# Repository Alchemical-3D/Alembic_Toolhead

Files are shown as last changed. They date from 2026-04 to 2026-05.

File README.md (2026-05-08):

<div align="center">

# 🧪 Alembic Toolhead







A highly specialized, ultra-lightweight toolhead designed for the Alchemical-3D ecosystem and A3DP gantry kits. Alembic replaces bulky fans with a rigid, compressed-air cooling architecture.  This toolhead is currently in the Alpha phase of development with working models.  Please review our **[Alpha State & Development Direction](ALPHA_&_DIRECTION.md)** document for more details on support, the project roadmap, and how to provide feedback.

<p align="center">
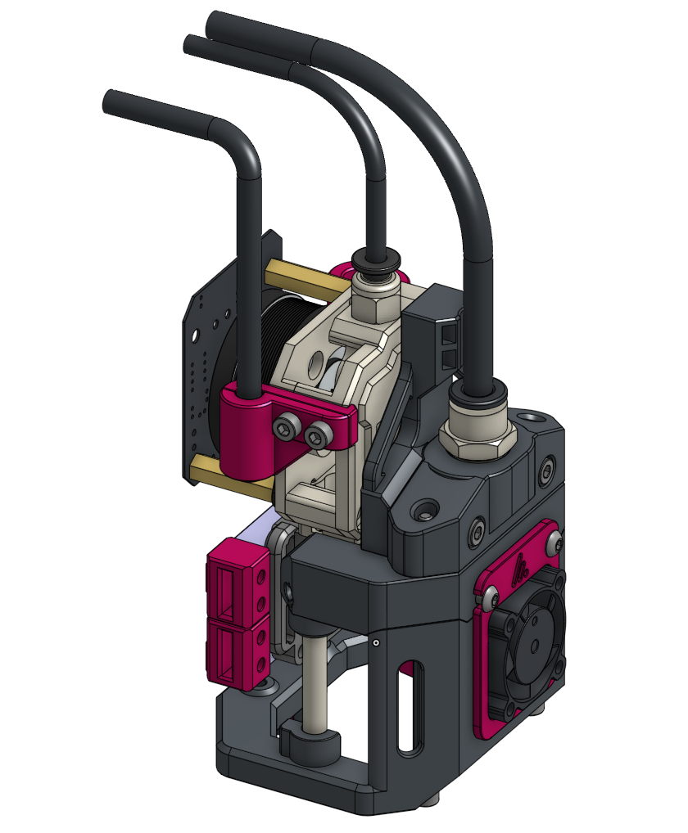
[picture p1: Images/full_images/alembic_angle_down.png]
Alembic Angle Down
  
  &nbsp;
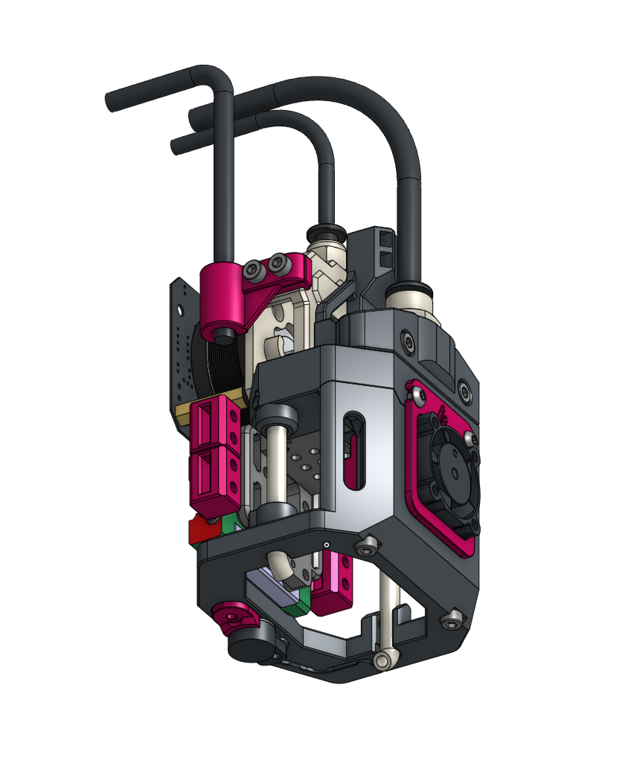
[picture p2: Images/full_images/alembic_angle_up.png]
Alembic Angle Up
  
</p>

**[Bill of Materials](BOM.md)** &nbsp;•&nbsp; **[Assembly Guide](Assembly_Guide.md)** &nbsp;•&nbsp; **[Print Settings](Print_Settings.md)**

</div>

<br>

---

## 🌬️ The Philosophy of Alembic

Alembic differentiates itself by dropping traditional bulky 4010 or 5015 part cooling fans entirely. Instead, it utilizes remote compressed air delivered through a pneumatic tube for high-performance part cooling. 

By integrating aluminum tubing directly into the structural integrity of the carriage, Alembic achieves a design that is incredibly lightweight, surprisingly rigid, and maximally compact—offering unobstructed visibility of the nozzle during layering.

> [!NOTE]
> **Sledgehammer vs. Scalpel**<br>
> *"While traditional systems focus on brute-forcing CFM to wash the area with ambient cooling, Alembic focuses on exact air placement and extreme air speed to achieve superior results. Where CPAP configs are the sledgehammer... Alembic is the scalpel."*

## ✨ Key Specifications & Features

- **Primary Extruder Support:** Initial geometry tailored for the **A3DP FXD**, but is being adopted for a wide range of support.
- **Standard Hotend:** Pre-configured for the **Takoto Hotend** but is being adopted for a wide range of support.
- **Part Cooling:** High-speed compressed air via a `6mm OD x 4mm ID` pneumatic tube pipeline. 
- **Hotend Cooling:** Powered efficiently by a single lightweight **2510 fan** *(for now...)*.
- **Umbilical Management:** Features dedicated, secure routing channels for **Chainflex (CAN/USB wiring)**, the primary pneumatic airline, and the PTFE filament tube.

> [!TIP]
> **Pneumatics and Compatible Systems**<br>
> *This toolhead uses pressurized air (similar to quiet aquarium or medical equipment pumps, rather than loud shop compressors). If you're interested in this project, check out the **[Pneuma Part Cooling](https://github.com/Alchemical-3D/Pneuma_Remote_Air)** project! It is a companion project from Alchemical-3D that provides a professional, quiet, and high-performance pneumatic air supply designed specifically to integrate seamlessly with Alembic.*

---

## 📚 Documentation Index

Everything you need to successfully replicate Alembic on your own machine:

| Category | Description |
| :--- | :--- |
| 📋 **[Bill of Materials (BOM)](BOM.md)** | The comprehensive checklist of printed parts, heat sets, hardware, and pneumatics needed. |
| 🛠️ **[Assembly Guide](Assembly_Guide.md)** | A fully-illustrated, step-by-step mastercloth for putting the Alembic together safely. |
| ⚙️ **[Print Settings](Print_Settings.md)** | Essential slicer configurations, material recommendations, and orientation rules. |
| 🧭 **[Alpha State & Direction](ALPHA_&_DIRECTION.md)** | Current hardware support, active development roadmap, and how to provide feedback. |

---

## 📸 Quick Glimpse

<p align="center">
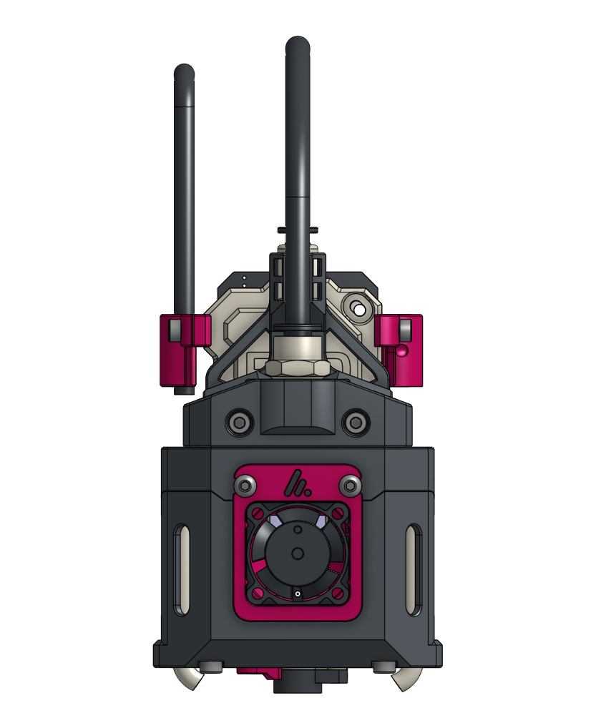
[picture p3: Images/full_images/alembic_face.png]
Alembic Face View
  
</p>

***

## ⚖️ License

This project is licensed under the **Creative Commons Attribution-NonCommercial-ShareAlike 4.0 International License**. See the [LICENSE.md](LICENSE.md) file for details.

***

> ☕ **Did you find this guide helpful?** 
> 
> My projects are open-source and free for the community. If you've enjoyed my designs and want to support my work, consider [leaving me a tip on Ko-fi](https://ko-fi.com/alchemical3d)! 
>
>

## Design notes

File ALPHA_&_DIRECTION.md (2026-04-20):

# 🧭 Alembic Toolhead: Alpha State & Development Direction

Alembic is currently in an active **Alpha State** of development. This document outlines the current state of the project, upcoming features, and intended paths forward as we progress toward a Beta release.

> [!WARNING]
> **Active Development Notice**  
> While we have working models that perform exceptionally well in testing, this toolhead is still evolving. Builders taking on the Alpha release should be prepared for changes to geometry, hardware requirements, or bill of materials (BOM) as the project matures.

---

## 🏗️ Current State (Alpha)

The Alembic Toolhead has proven the viability of utilizing high-speed, remote compressed air for precise high speed part cooling rather than traditional blowers. 

### Current Hardware Compatibility

- **Extruders:** Currently designed for the **A3DP FXD** extruder.
- **Hotends:** Direct support built-in for the **Takoto** and **Dragon** hotends. 

We expect hardware compatibility to widen significantly throughout alpha and beta testing.

---

## 🗺️ Roadmap & Intended Changes

As we prepare the transition from Alpha to Beta, significant improvements are being evaluated and staged. Below is an active list of concepts and intended upgrades going forward:

> [!NOTE]
> ### 📝 Highlighted Concepts & Planned Features
> 
> *The following are concepts, modular expansions, and hardware additions currently under active investigation and development.*
> 
> - **Expanded Extruder Compatibility:** Designing adapters and core mounts to support a wider array of popular extruders beyond the A3DP FXD.
> - **Expanded Hotend Compatibility:** Bringing support for additional high-flow and standard hotends beyond Takoto and Dragon. 
> - **Airflow Optimization:** Continuous iterations and tuning to the internal pneumatic routing to maximize cooling efficiency.
> - **Weight Reduction & Structural Tuning:** Refining the carriage geometry to shave off extra grams without sacrificing the rigidity.

*(Note: Features and concepts listed here are subject to change based on testing constraints, empirical results, and community feedback.)*

---

## 📣 We Need Your Feedback!

Because Alembic relies heavily on unconventional methodology, **community feedback is exceptionally helpful** for optimizing the performance of the toolhead.

If you are an Alpha builder or are interested in the project, we want to hear from you! Please share your prints, airflow observations, and suggestions for improvements.

### Join the Conversation

All development discussion, testing feedback, and suggestions should be directed to our community Discord server.

👉 **Join the discussion in the `#alembic-toolhead` channel on the Alchemical-3D Discord!**

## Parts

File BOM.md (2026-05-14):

# Bill of Materials (BOM)

This list contains all the 3D-printed and physical hardware required to assemble the Alembic Toolhead.

*Note: This document contains affiliate links. Sourcing your parts through these links helps support the continued development of this and other projects at no cost to you, and in some cases gets a discount!*

*Note: Quantities for some hardware fasteners (e.g. M3 screws, heat inserts) are estimates and may be slightly higher/lower based on your exact A3DP FXD extruder/carriage configuration.*

## 1. Printed Parts
Print these out using the guidelines specified in the [Print Settings](Print_Settings.md) page.

| Part File Name | Qty | Description / Notes |
| --- | :---: | --- |
| `Lower_Body.stl` | 1 | Main lower chassis. |
| `Manifold_Frame.stl` | 1 | Pneumatic cooling mechanisms. |
| `Fan_Baffle_Takoto.stl` | 1 | Specifically for the Takoto. |
| `Chainflex_Clamp_Main.stl` | 1 | Top clamp for the electrical umbilical. |
| `Chainflex_Clamp_Base.stl` | 1 | Base support for the electrical umbilical. |
| `Pnuematic_Strain_Relief.stl`| 1 | Secures the pneumatic tube. |
| `Sensor_Retainer.stl` | 1 | Retains BDsensor. (optional) |
| `BD_Mod_Clamp.stl` | 1 | Mod clamp for BDsensor. (optional) |
| `Shim_06mm_BDsensor.stl` | 1 | 0.6mm shim for BDsensor offset. (optional) |
| `Bend_Tool_Base.stl` | 1 | Jig tool base for bending tubing. |
| `Bend_Tool_Lever.stl` | 1 | Jig tool lever for bending tubing. |

## 2. Fasteners & Physical Hardware

| Item | Qty (Est.) | Description |
| --- | :---: | --- |
| **[M3 Heat Set Inserts](https://kb-3d.com/store/inserts-fasteners-adhesives/278-brass-heat-set-threaded-insert-for-plastic-m3x5x4mm.html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)** | ~4 | Standard M3 (typically 5mm x 4mm). Needed at Intake and Strain Relief. |
| **[M3 x 65mm Cap/Button Head](https://amzn.to/4vQRHtp)** | ~2 | Full length of the toolhead carriage, vertically. |
| **[M3 x 8mm Cap/Button Head](https://amzn.to/3QIvw8G)** | ~8 | General assembly screws. |
| **[M3 x 20mm Cap/Button Head](https://amzn.to/3QIvw8G)** | ~2 | For securing the pneumatic strain relief. |
| **[M3 x 24mm Cap/Button Head](https://amzn.to/3QIvw8G)**| ~2 | Passing through front of fan baffle and manifold into the carriage. |
| **[M3 Grub Screws](https://kb-3d.com/store/inserts-fasteners-adhesives/870-alloy-set-screw-m3-x-05-x-4mm-cup-point-1656776837904.html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)** | ~2 | Secure the aluminum tubes into the lower body. |
| **[Aluminum Tube 5mm OD x 3mm](https://amzn.to/4ntsNw5)** | 2 |~ 55mm ID Aluminum tube. |
| **[O-Ring 9x2 (23/64 x 5/64)"](https://amzn.to/4d411CT)** | 2 | For pneumatic sealing. Check diameter against the printed groove. |
| **[PTFE Bowden Fitting](https://kb-3d.com/store/e3d/313-e3d-threaded-bowden-coupling-175-1644689893776.html?affp=6182)** | 1 | PC4-M10 Bowden Pass-Through |
| **[Part Cooling Tube](https://amzn.to/4cFbqoF)** | 1 | 6mm OD x 4mm ID Pneumatic Tube and fittings. |
| **[M2 Heat Set Inserts](https://kb-3d.com/store/inserts-fasteners-adhesives/602-brass-heat-set-threaded-insert-for-plastic-m2x35x3mm-1656874172023.html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)** | ~2 | Standard M2 (typically 3.5mm x 3mm). Probe mount only. (Optional) |
| **[M2 x 10mm BHCS](https://amzn.to/4vUwuis)** | ~1 | For securing the BDsensor retainer and clamp. (Optional) |
| **[M2 x 8mm BHCS](https://amzn.to/4vUwuis)** | ~1 | For securing the BDsensor retainer and clamp. (Optional) |

## 3. Electronics and Hardware

| Item | Qty | Description |
| --- | :---: | --- |
| **[Extruder](https://advanced3dprinting.com/products/fxd)** | 1 | A3DP FXD Extruder (Supports NEMA 14). |
| **[Hotend](https://advanced3dprinting.com/products/takoto-hotend?_pos=3&_sid=1122f6a8f&_ss=r)** | 1 | Takoto/Dragon Hotend. |
| **[Hotend Cooling Fan](https://kb-3d.com/store/fans/3684-2510-ball-bearing-cooling-fan-24v-1740693669311.html?affp=6182)** | 1 | 2510 Fan for the Takoto/Dragon heatbreak. |
| **[Filament Umbilical Tube](https://kb-3d.com/store/hardware/238-ptfe-tubing-3125-id-4762-od-black-per-foot.html?affp=6182)** | 1 | Standard PTFE Bowden Tube. |
| **[CAN / Wiring Umbilical](https://kb-3d.com/store/wiring-connectors/792-igus-chainflex-control-cable-cf9-05-04-per-foot-1674670790036.html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)** | 1 | Igus Chainflex cable. |
| **[Bed Probe (Optional)](https://www.pandapi3d.com/product-page/bed-distance-sensorm)** | 1 | BDsensor. |

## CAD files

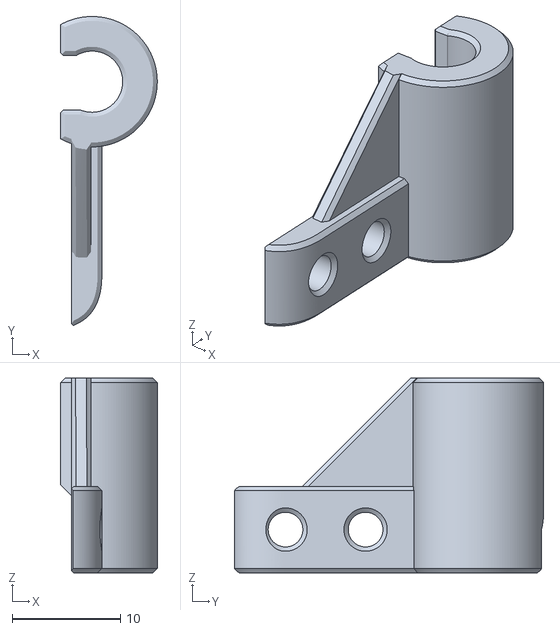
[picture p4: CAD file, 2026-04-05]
STL_Files/Chainflex_Clamp_Main.stl
8.92 x 28.6 x 18.0

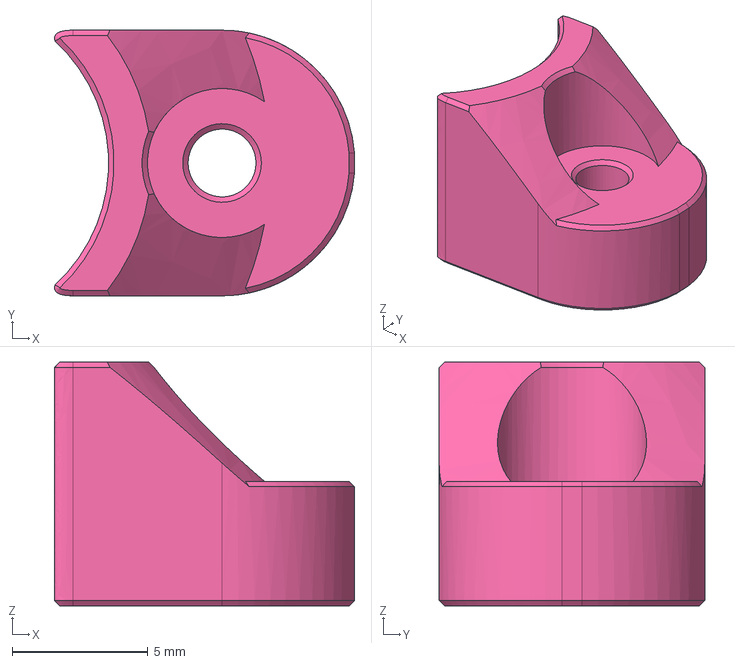
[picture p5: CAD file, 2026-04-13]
STEP_Files/Sensor_Retainer_Dragon-MZE.step
11.1 x 9.80 x 9.00 mm

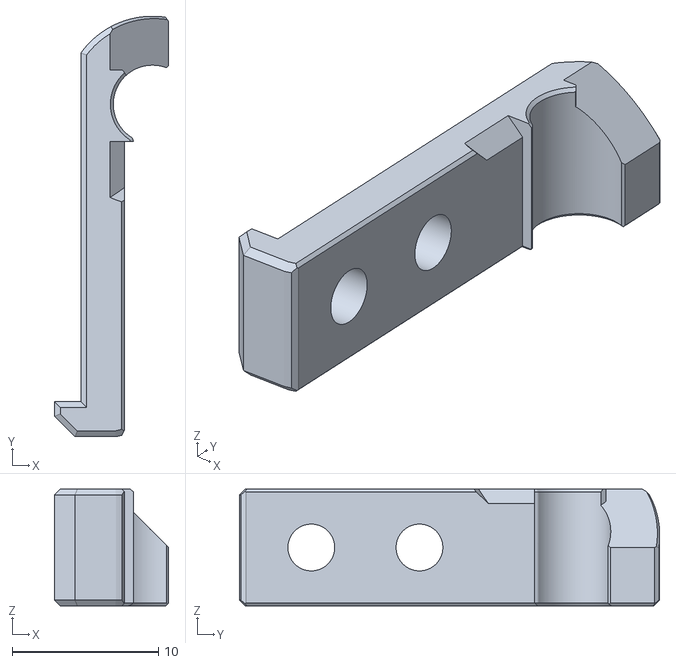
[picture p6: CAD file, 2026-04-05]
STL_Files/Chainflex_Clamp_Base.stl
7.80 x 28.8 x 8.00

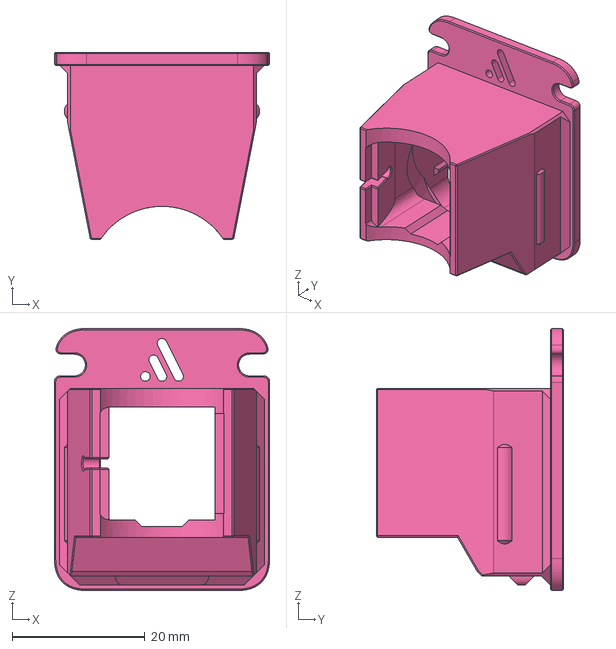
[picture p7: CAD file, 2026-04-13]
STEP_Files/Fan_Baffle_Dragon.step
32.4 x 28.2 x 39.4 mm

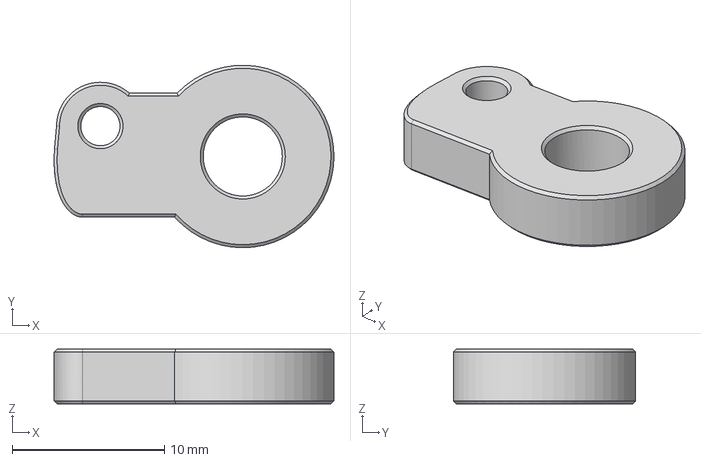
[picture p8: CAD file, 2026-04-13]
STEP_Files/Shim_56_BDsensor_Dragon-MZE.step
18.4 x 12.0 x 3.60 mm

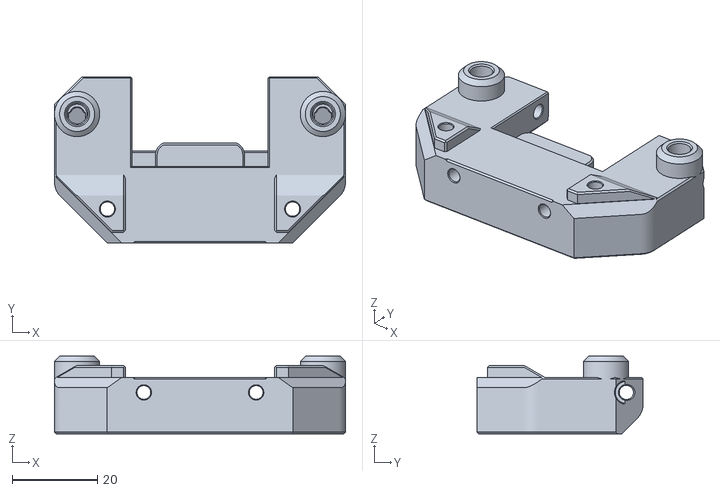
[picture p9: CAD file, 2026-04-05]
STL_Files/Manifold_Frame.stl
68.2 x 39.0 x 18.2

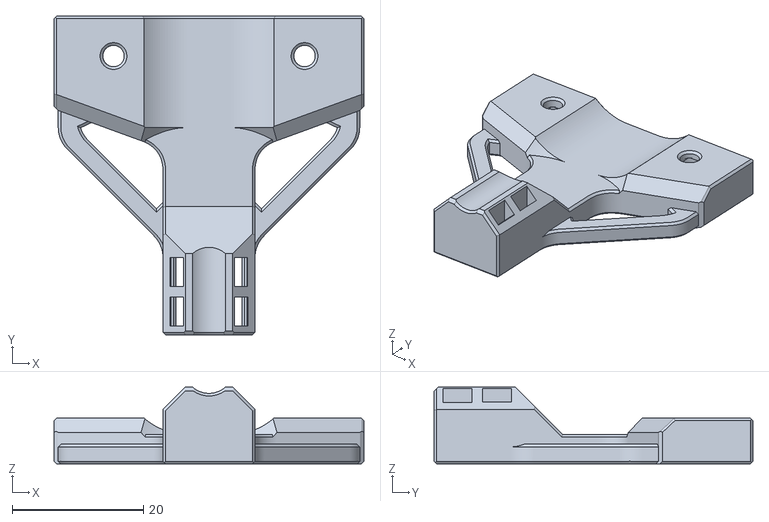
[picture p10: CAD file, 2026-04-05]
STL_Files/Pnuematic_Strain_Relief.stl
47.2 x 48.6 x 11.7

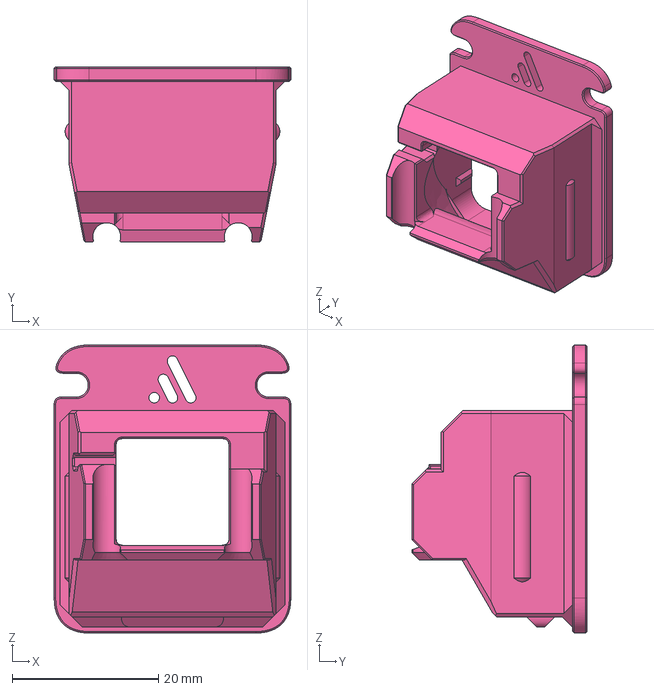
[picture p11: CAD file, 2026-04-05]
STEP_Files/Alembic_Toolhead_V201 - Fan_Baffle_Takoto.step
32.4 x 24.0 x 39.4 mm

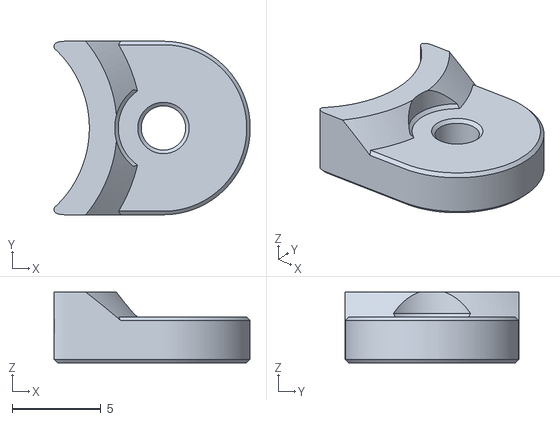
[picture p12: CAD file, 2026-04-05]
STL_Files/Sensor_Retainer.stl
11.1 x 9.80 x 4.00

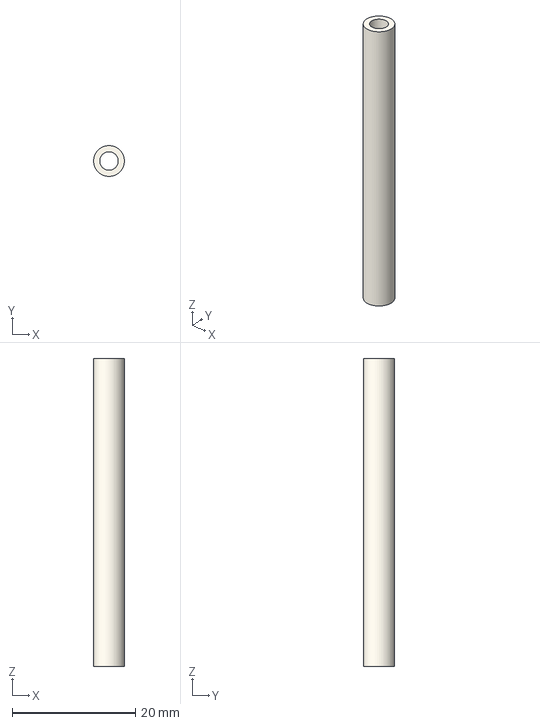
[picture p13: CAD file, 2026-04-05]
STEP_Files/Alembic_Toolhead_V201 - 5mmODX3mmID_Alu_Tube.step
5.00 x 5.00 x 50.0 mm

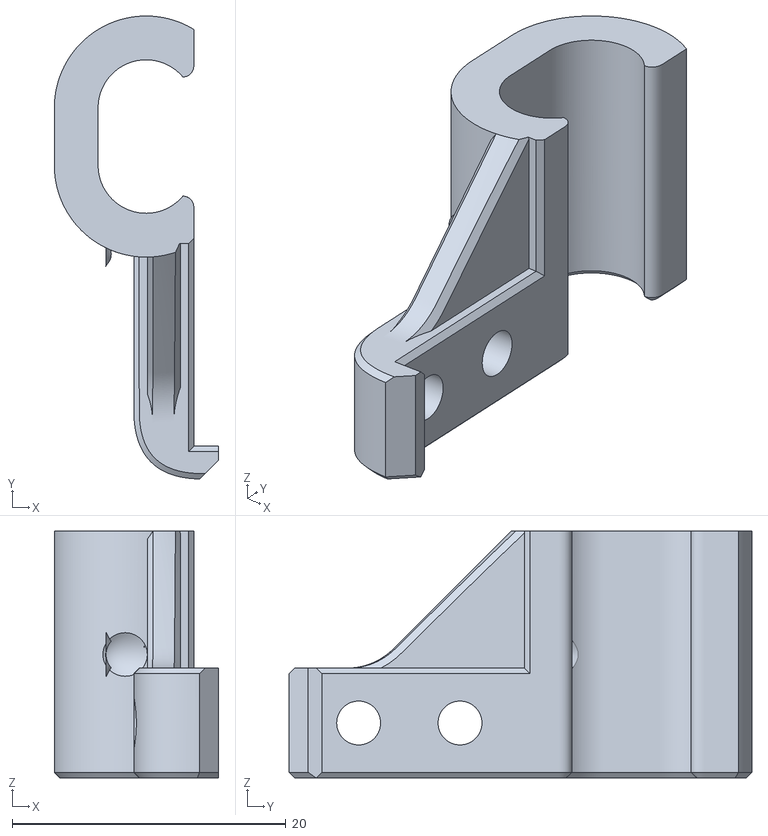
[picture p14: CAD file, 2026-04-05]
STL_Files/BD_Mod_Clamp.stl
12.0 x 33.8 x 18.0

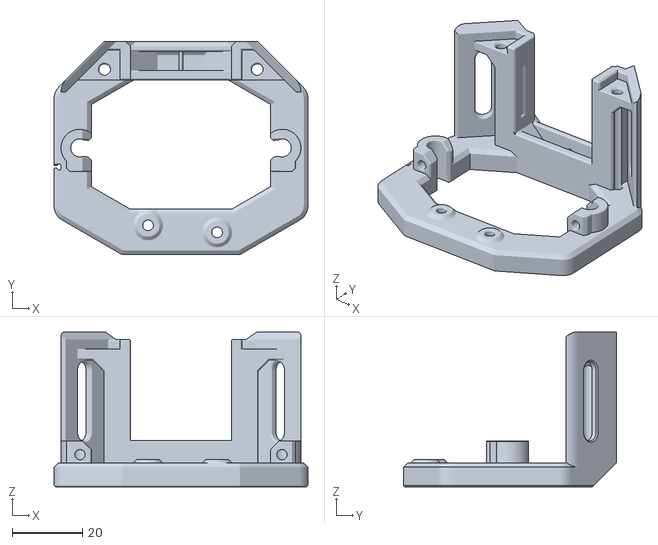
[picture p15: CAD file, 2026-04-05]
STL_Files/Lower_Body.stl
72.2 x 60.6 x 44.0

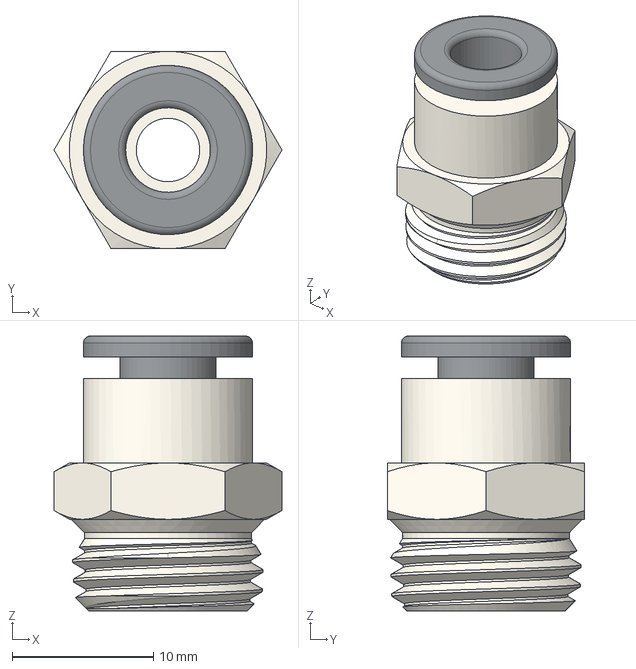
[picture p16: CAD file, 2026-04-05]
STEP_Files/Alembic_Toolhead_V201 - Pnuematic_Fitting_6mmOD.step
16.2 x 14.0 x 19.5 mm

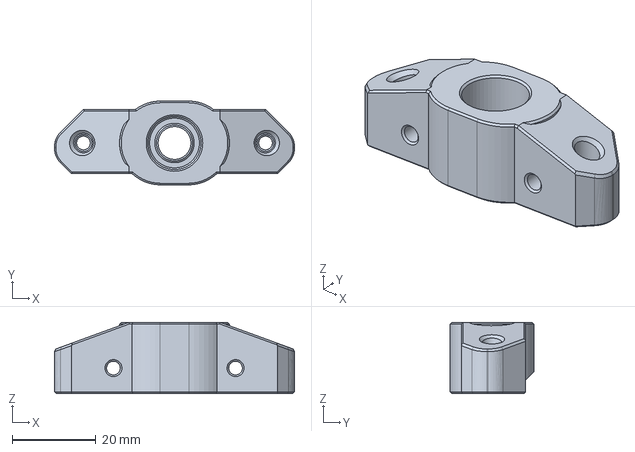
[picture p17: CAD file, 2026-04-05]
STEP_Files/Alembic_Toolhead_V201 - Intake_6mmOD.step
57.2 x 20.0 x 17.0 mm

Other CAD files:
STEP_Files/Alembic_Toolhead_V201 - Chainflex_Clamp_Main.step
STEP_Files/Alembic_Toolhead_V201 - Manifold_Frame.step
STL_Files/Fan_Baffle_Takoto.stl
STL_Files/Bend_Tool_Base.stl
STEP_Files/Alembic_Toolhead_V201 - BD_Mod_Clamp.step
STEP_Files/Alembic_Toolhead_V201 - Belt_Clamp_9mm.step
STEP_Files/Alembic_Toolhead_V201 - Chainflex_Clamp_Base.step
STEP_Files/Alembic_Toolhead_V201 - Lower_Body.step
STEP_Files/Alembic_Toolhead_V201 - NEMA14_.step
STEP_Files/Alembic_Toolhead_V201 - PC4-M10 Bowden Pass-Through.step
STEP_Files/Alembic_Toolhead_V201 - Pnuematic_Strain_Relief.step
STEP_Files/Alembic_Toolhead_V201 - Sensor_Retainer.step
STEP_Files/Alembic_Toolhead_V201 - Shim_06mm_BDsensor.step
STEP_Files/Bend_Tool_Lever.step
STEP_Files/Part Studio 1 - Bend_Tool_Base.step
STL_Files/Bend_Tool_Lever.stl
STL_Files/Fan_Baffle_Dragon.stl
STL_Files/Sensor_Retainer_Dragon-MZE.stl
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

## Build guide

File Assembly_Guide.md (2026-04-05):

# Alembic Assembly Guide

Welcome to the assembly guide for the Alembic toolhead. 

> [!CAUTION]
> **Important Torque Notice:**
> The milled portions of this toolhead are **aluminum**—this includes the carriage, the extruder, and the mounting plate for the hotend. Fasteners going into these aluminum parts can be tightened to proper torques ~ 1.2 Nm (10.6 in-lbs).
> 
> However, **the rest of the parts are 3D-printed and SHOULD NOT be overtightened.** Stop turning as soon as the plastic begins to compress.

---

## Preparation: Tubing Bending Jig

To ensure proper airflow and alignment to the nozzle tip, the 5mm OD aluminum tubes must be bent to profiles without crimping the walls. 

A set of simple but specialized 3D-printable tools (`Bend_Tool_Base.stl` and `Bend_Tool_Lever.stl`) are provided in the project files to make this process easier:

1. Print the base and lever parts with four or more walls and high infill (40%+ infill) so they don't flex under pressure.

2. Measure the distance from tube passthrough on the lower body and the edge of the heatblock. Divide this distance by two. This is the distance you will need to insert the tube into the jig to where the bend begins.

3. Seat your straight aluminum tube firmly inside the starting channel on the **Bend Tool Base** using the previous measurement.

4. Slide the **Bend Tool Lever** over the tube and apply smooth, continuous pressure to wrap it around the jig's curve until it matches the final shape.

> [!TIP]
>
> **Bend Support:** In its current form, the ID of the aluminum tube is 3mm if you have issues with the tube deforming and blocking airflow, you can insert a <3mm rod into the tube to provide support during bending.  A great option for this are the 2.8mm plastic welding rods, which are usually easy to remove post bend.
>
> **Tool Spacing:** There should be about 5-10mm of space between the two tools when starting to bend. This avoids tool breakage and provides sufficient room for the bend to follow the curve of the tool.

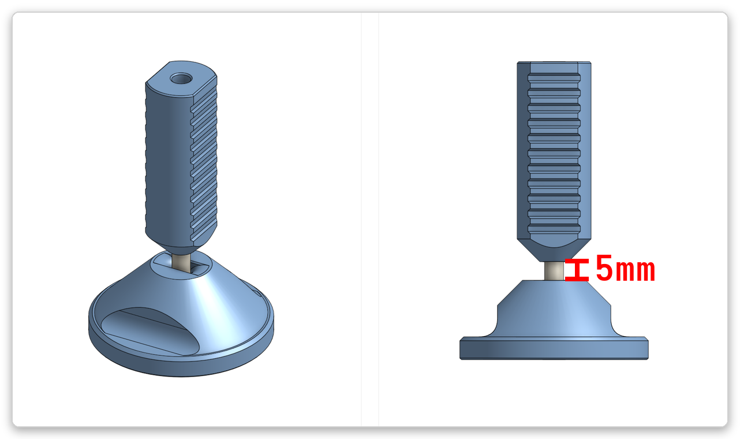
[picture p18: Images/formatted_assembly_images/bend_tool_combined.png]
Tubing Bend Tool
<br>
*Fig. 1: Example of tubing bend tool layout emphasizing the initial 5mm spacing.*

---

## Preparation: Heat Set Inserts

Install the M3 heat set inserts into your printed parts and add the upper o-ring to the intake before threading the pnuematic fitting. 

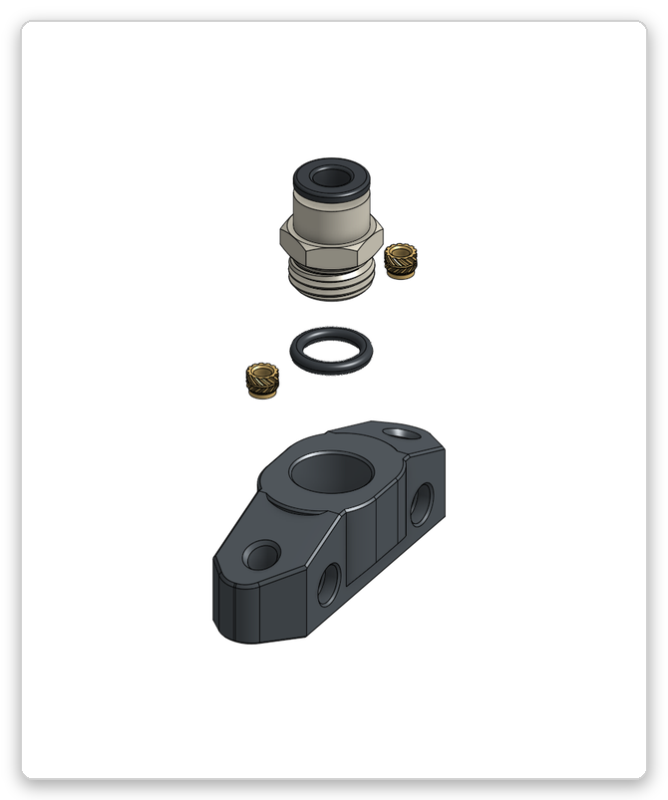
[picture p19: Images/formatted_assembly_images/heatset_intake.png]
Heat-Set Intake
<br>
*Fig. 2: Install (2) M3 inserts into the intake component.*

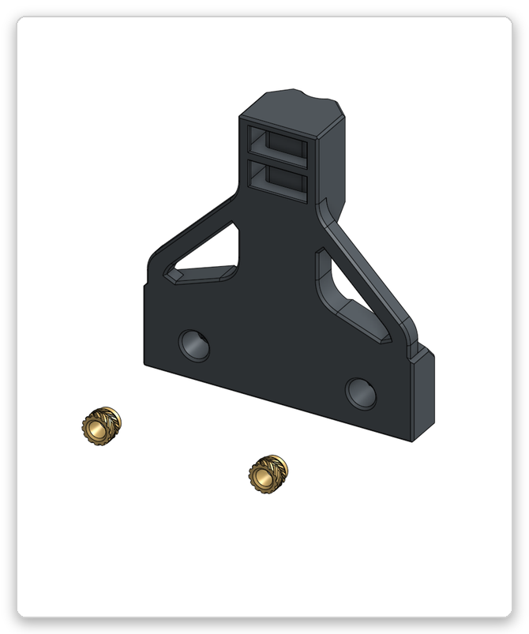
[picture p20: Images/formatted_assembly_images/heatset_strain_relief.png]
Heat-Set Strain Relief
<br>
*Fig. 3: Install (2) M3 inserts into the strain relief block.*

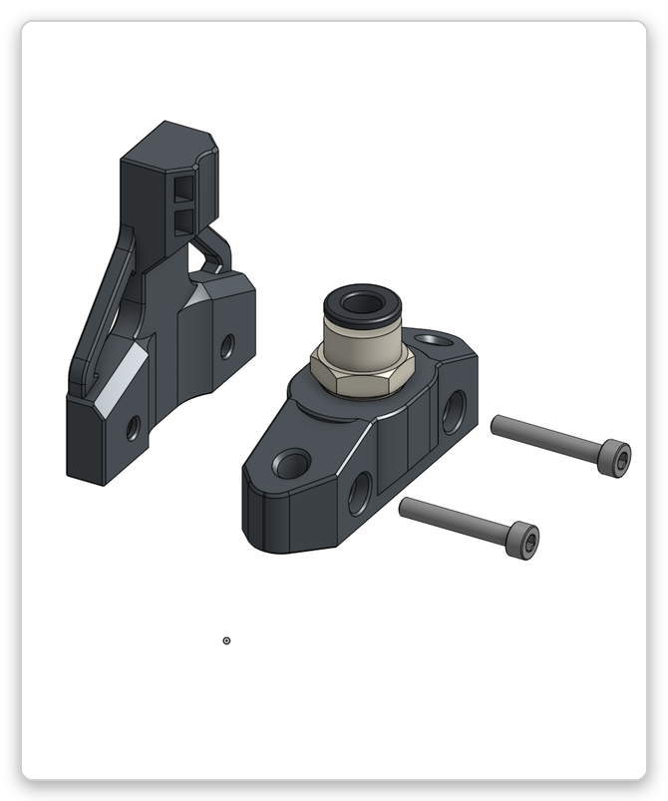
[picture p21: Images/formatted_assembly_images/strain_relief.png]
Chainflex Clamp Assembly
<br>
*Fig. 4: Assemble strain relief and intake.*

---

## Step 1: Main Body and Tubing

Insert the aluminum tubes.
> [!TIP]
> 
>Due to alignment requirements, the tubes will actually rotate about 5 degrees to ensure they directly point towards the nozzle tip.   Ensure the vertice of the air path is directly under the nozzle tip, but the tubes themselves are above nozzle face level to avoid impact with prints. 

Ensure you use the O-ring to get a proper seal for the compressed air when tying the whole assembly together. 

After merging the manifold and lower body, add grub screws to lock the tubes in place. 

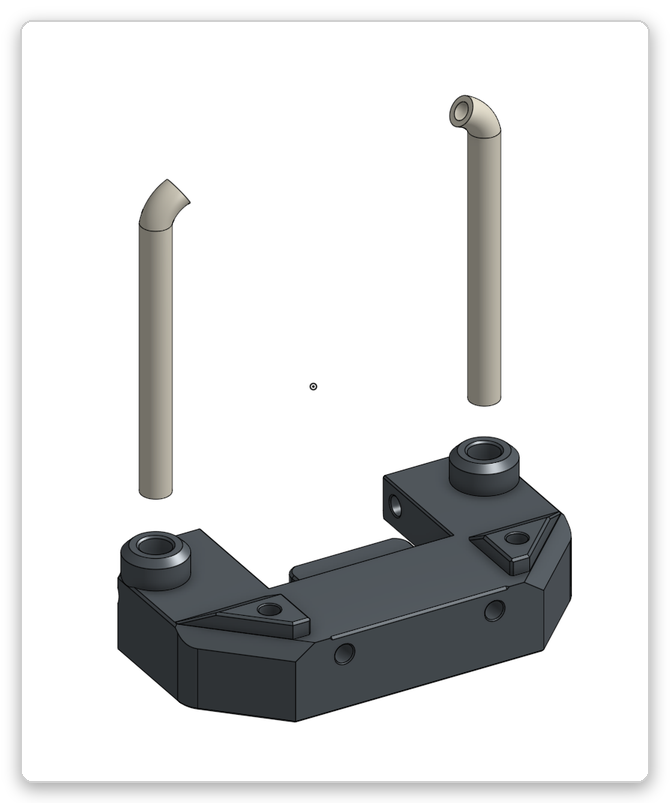
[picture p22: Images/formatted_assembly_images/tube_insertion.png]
Tube Insertion
<br>
*Fig. 5: Insert the primary tubing into the main body.*

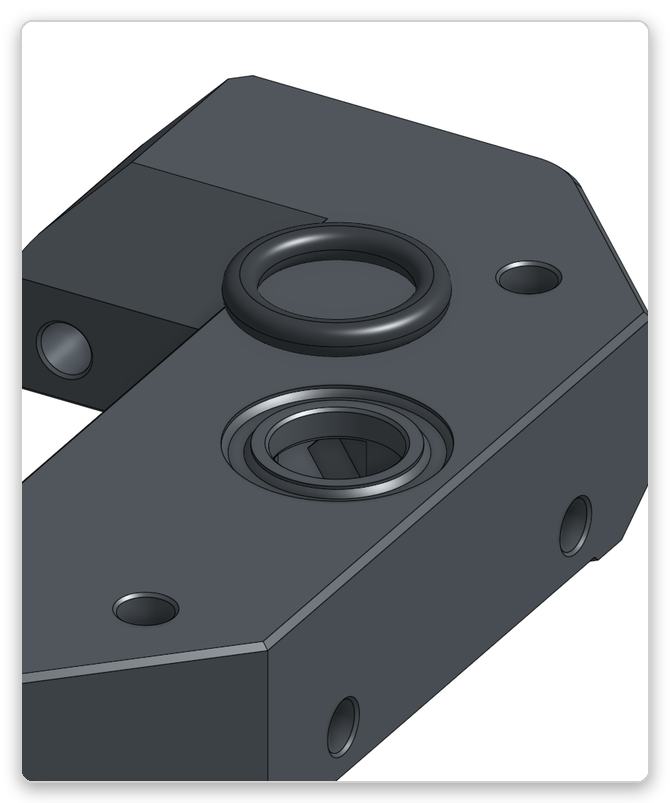
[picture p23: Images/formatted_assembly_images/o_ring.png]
O-Ring Seating
<br>
*Fig. 6: Ensure the O-ring is properly seated for an airtight seal.*

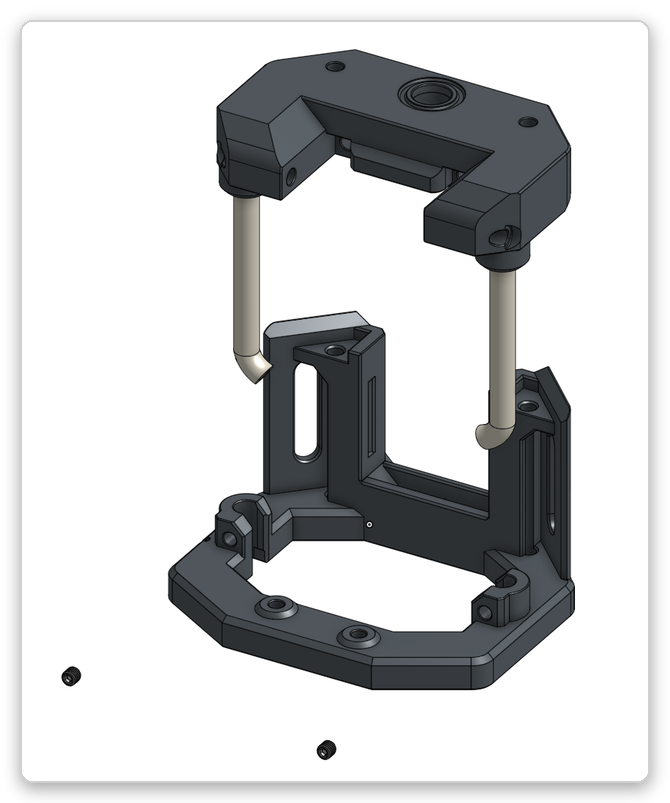
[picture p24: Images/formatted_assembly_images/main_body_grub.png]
Grub Screw
<br>
*Fig. 7: Secure the assembly with grub screws, but remember not to crush the tubing.*

---

## Step 2: Vertical Assembly and Mounting

Now join the lower body with your toolhead carriage.

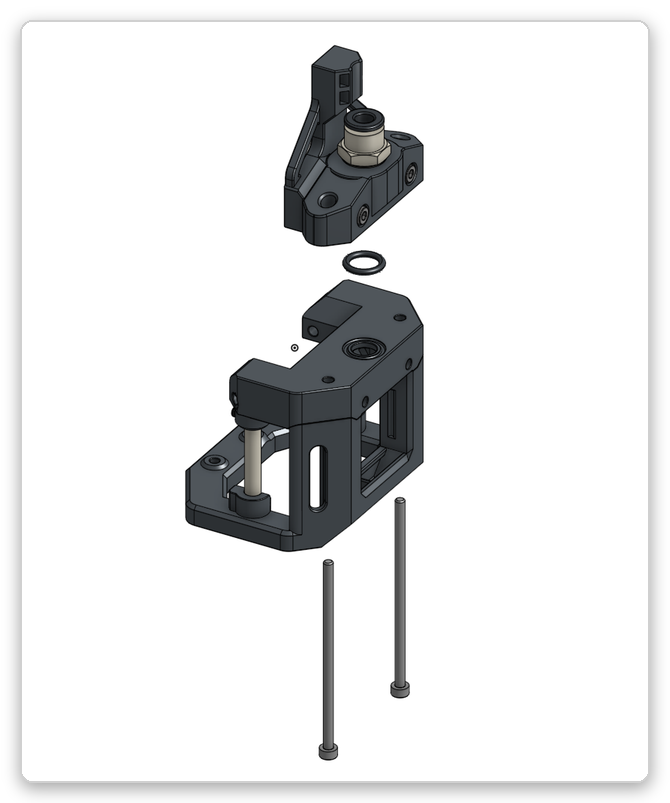
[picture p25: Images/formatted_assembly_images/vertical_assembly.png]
Vertical Assembly
<br>
*Fig. 8: Align the vertical bodies and tie together with the 65mm M3 BHCS screws.*
> [!TIP]
> 
>During this step you add the central O-ring between the intake and the manifold, this is easier to do by placing the manifold on the mount and setting the ring on it, before bringing the parts together.  Alignment of this o-ring is critical to ensure a proper seal.

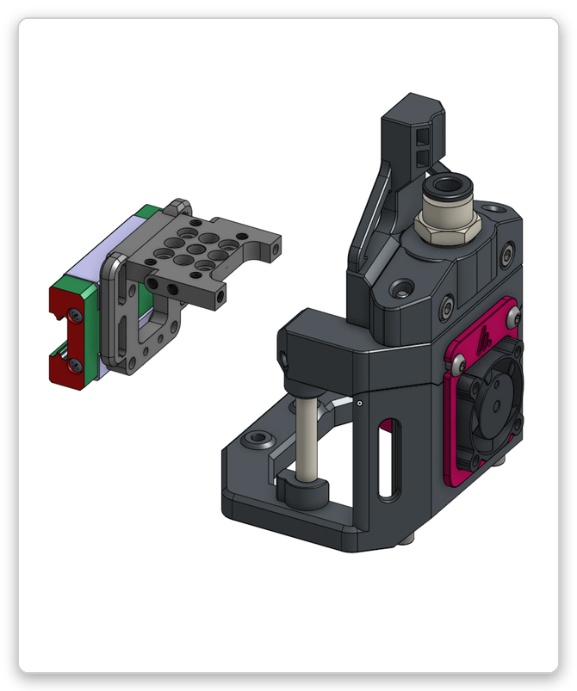
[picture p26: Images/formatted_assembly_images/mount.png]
Mount
<br>
*Fig. 9: Apply screws connecting the main Alembic body to the aluminum carriage mount.*

---

## Step 3: Hotend Baffle and 2510 Fan

The 2510 fan mounts inside the housing toolless and will snap in place. The full assembly also snaps in place but is secured with two M3 BHCS screws to the carriage. 

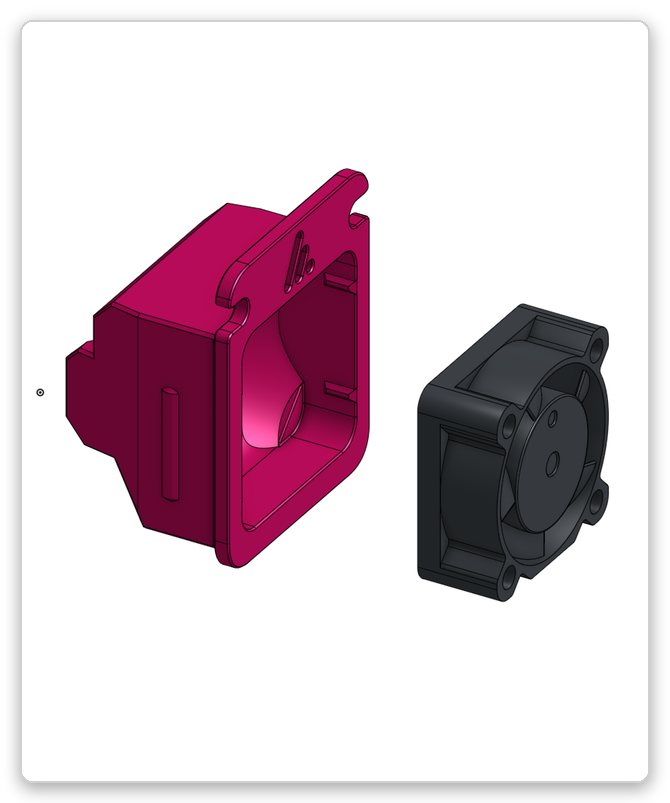
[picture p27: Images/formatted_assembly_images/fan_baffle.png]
Fan Baffle
<br>
*Fig. 10: Slide the 2510 fan into the toolless housing, then position the hotend baffle.*

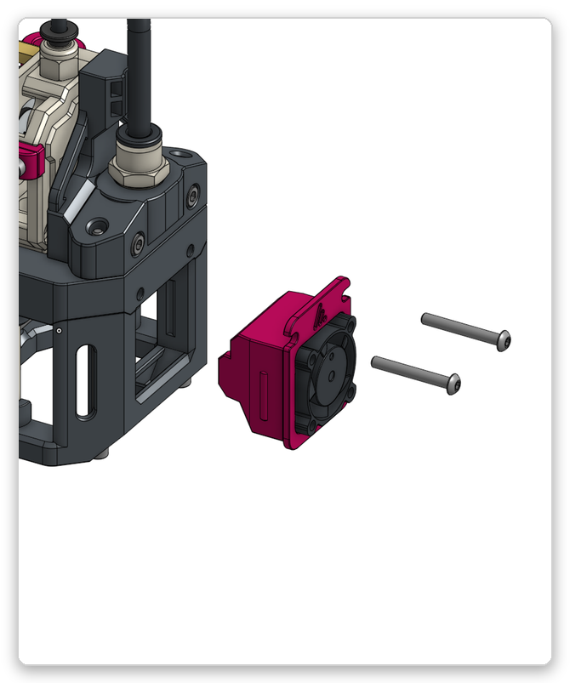
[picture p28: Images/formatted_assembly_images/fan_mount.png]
Fan Mount
<br>
*Fig. 11: Attach the full baffle assembly to the carriage using two M3 BHCS screws.*

---

## Step 4: Umbilical Strain Relief

Alembic utilizes an advanced umbilical featuring Chainflex (for CAN), a pneumatic tube, and a PTFE filament path. While there is strain relief for these other components, the primary relief is provided by this assembly and fastening the entire umbilical package together.

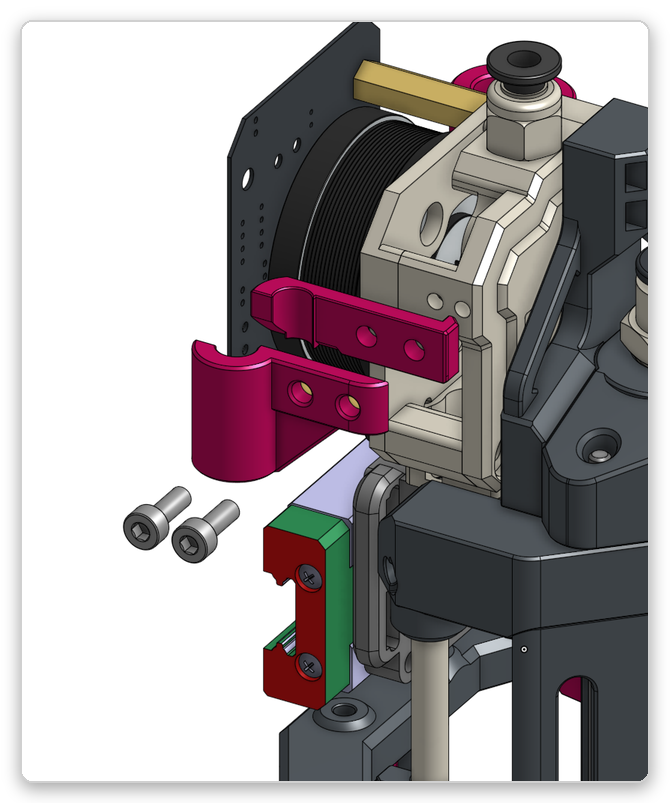
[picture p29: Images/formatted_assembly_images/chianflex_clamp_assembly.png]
Strain Relief
<br>
*Fig. 12: Attach the chainflex strain relief.*

---

## Optional: BDsensor Installation

If you are using a BDsensor, install the retainer and clamp. A 0.6mm shim is provided if your hotend-to-probe offset needs adjustment.

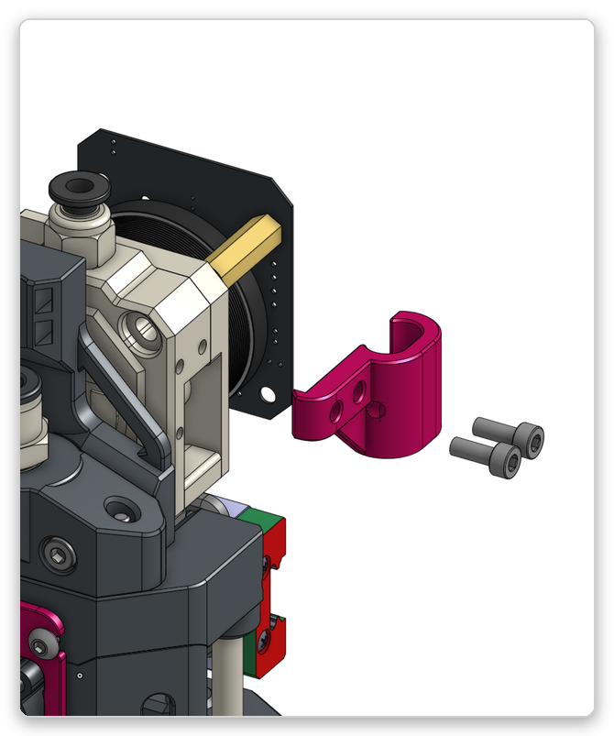
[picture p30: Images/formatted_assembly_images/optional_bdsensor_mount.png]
Optional BDsensor Mount
<br>
*Fig. 13: Attach the BDsensor along with the necessary shims/clamps.*

---

### End of Assembly
The Alembic toolhead is now assembled.

***

> ☕ **Did you find this guide helpful?** 
> 
> My projects are open-source and free for the community. If you've enjoyed my designs and want to support my work, consider [leaving me a tip on Ko-fi](https://ko-fi.com/alchemical3d)! 
>
>

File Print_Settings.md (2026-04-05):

# Print Settings for Alembic

The structural parts of the Alembic Toolhead should be printed in rigid, temperature-resistant materials. We strongly recommend **ABS, ASA, or PC** to withstand the thermal environment near the hotend and carriage.

## Slicer Recommendations (0.4mm Nozzle)

Below are the suggested values for a functional print between weight, strength, and print duration.

| Parameter | Recommended Value |
| --- | --- |
| **Layer Height** | 0.2mm |
| **Extrusion Width** | 0.4mm - 0.45mm |
| **Wall Perimeters** | 4 (minimum) |
| **Top / Bottom Solid Layers** | 5 Top / 5 Bottom |
| **Infill Type** | Grid, Gyroid, or Rectilinear |
| **Infill Percentage** | 40% |
| **Supports** | None. |

### Pro-Tips
- **Shrinkage Compensation:** If using ABS/ASA, remember to ensure your filament flow and scaling are dialed in so bearings and screws fit snugly without cracking the plastic, you can also print out a common 20mm cube to adjust your filament shrinkage as required.
- **Cooling:** Depending on your current printer, use minimal part cooling to ensure excellent layer adhesion for structural integrity.

Once you have your parts printed, proceed to the [Assembly Guide](Assembly_Guide.md) and check your [Bill of Materials](BOM.md) for required hardware.

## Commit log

2026-03-25 Enhance README with detailed toolhead description
    Expanded description of the toolhead's capabilities.
2026-04-04 Create STL
    Folder for STL files.
2026-04-05 Revise README with new toolhead details and layout
    Updated README to enhance content and structure, including new sections and images.
2026-04-05 Revise print settings and recommendations in documentation
    Updated slicer recommendations and pro-tips for printing settings.
2026-04-05 Update README with pneumatic system details
    Added a note about the pneumatic system used in the toolhead, clarifying its operation and mentioning a related project.
2026-04-05 Update README with pneumatic systems note
    Added a note about pneumatic systems and their operation.
2026-04-05 Revise Pneumatics note for clarity and detail
    Updated the note on Pneumatics to include noise reduction features.
2026-04-05 Fix torque notice formatting in assembly guide
2026-04-20 Refine descriptions in ALPHA_&DIRECTION.md
    Removed nozzle exit geometry from airflow optimization details and simplified weight reduction description.
2026-04-24 Update links for various BOM items
2026-04-30 Update pneumatics section for clarity
    Clarified information about pneumatics and noise in the README.
2026-05-08 Fix duplicate Pneumatics and Compatible Systems section
2026-05-14 Fix link for Aluminum Tube in BOM.md
    Updated the link for the Aluminum Tube 5mm OD x 3mm.

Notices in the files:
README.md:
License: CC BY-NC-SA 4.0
